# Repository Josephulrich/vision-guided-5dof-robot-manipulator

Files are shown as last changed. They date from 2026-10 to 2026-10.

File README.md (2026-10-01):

# Robot manipulateur 5 axes guidé par vision

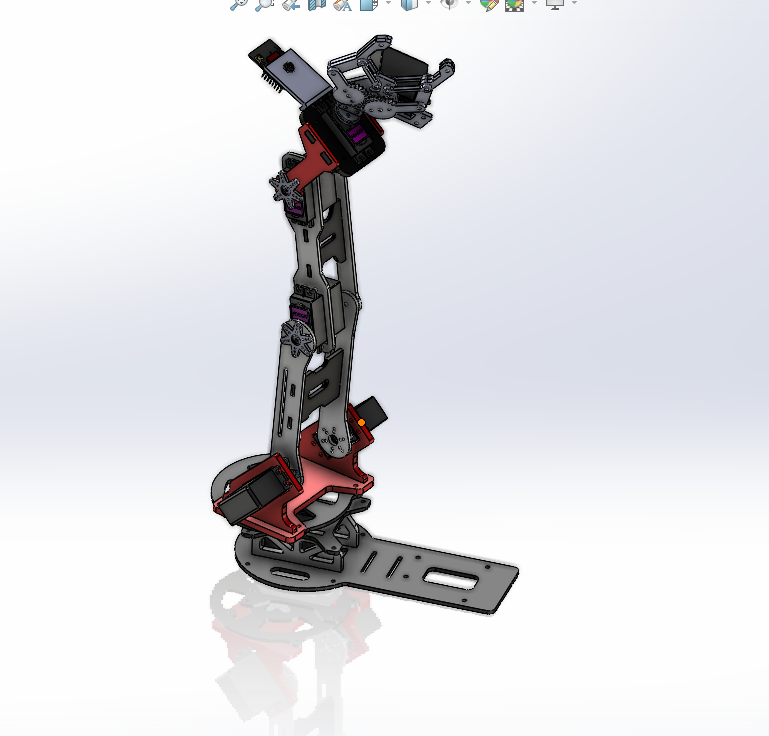
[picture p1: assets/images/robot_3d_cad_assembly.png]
Assemblage CAO du robot


Bras manipulateur robotisé à 5 degrés de liberté conçu pour détecter, atteindre et saisir des objets à l’aide d’une caméra, d’une pince motorisée et d’une chaîne de commande basée sur Arduino Mega.

Le projet réunit la conception mécanique sous SolidWorks, l’impression 3D de pièces en PLA, le dimensionnement des actionneurs, l’électronique de commande, la programmation embarquée, l’étude cinématique selon Denavit–Hartenberg, le pilotage via MATLAB et une base de vision par ordinateur développée en Python.

---

## Vue d’ensemble

| Élément | Description |
|---|---|
| Architecture robotique | Bras manipulateur série à 5 axes de type R-R-R-R-R |
| Fonction principale | Détection, positionnement et saisie d’objets |
| Structure mécanique | 3 segments principaux, 5 articulations et une pince motorisée |
| CAO | SolidWorks |
| Fabrication | Impression 3D en PLA |
| Contrôle bas niveau | Arduino Mega et Arduino IDE |
| Cinématique | Modèle Denavit–Hartenberg et trajectoires MATLAB |
| Vision | Caméra embarquée et développement de reconnaissance d’images en Python |
| Actionneurs | Servomoteurs MG995R-360°, MG996R, S07NF et servo de pince |
| Documentation | Rapport complet disponible dans le repository |

---

## Objectif du projet

L’objectif était de concevoir et de réaliser un manipulateur robotisé à cinq axes capable d’interagir avec son environnement.

Le système vise à :

- Détecter ou localiser un objet à partir d’une caméra.
- Calculer une configuration ou une trajectoire permettant au robot d’atteindre la zone ciblée.
- Commander les servomoteurs pour positionner les différents segments du bras.
- Actionner une pince afin de saisir l’objet.
- Valider les mouvements, les positions particulières et la cinématique développée sous MATLAB.

Le projet a été réalisé en première année du cycle ingénieur. Il a couvert l’étude, la conception, la fabrication, l’assemblage, la programmation et la modélisation MATLAB. La durée rapportée est d’environ deux semaines, soit 334 heures de travail cumulées.

---

## Architecture mécanique

Le robot est constitué de trois segments principaux et de cinq articulations rotatives en série.

```text
Base → Bras principal → Avant-bras → Poignet → Pince
```

### Actionneurs et dimensionnement

| Référence | Fonction | Couple calculé | Actionneur sélectionné |
|---|---|---:|---|
| `SM1` | Rotation de la base | 6,31 kg·cm | MG995R — rotation 360° |
| `SM2` | Bras principal | 6,31 kg·cm | MG996R |
| `SM3` | Avant-bras | 2,44 kg·cm | MG996R |
| `SM4` | Poignet | 0,22 kg·cm | S07NF |
| `SM5` | Ouverture / fermeture de la pince | — | Micro-servomoteur rotatif |

Les pièces ont été modélisées sous SolidWorks, puis exportées au format STL pour l’impression 3D. Les fichiers source SolidWorks et les modèles d’impression sont inclus dans le repository.

### Vue éclatée

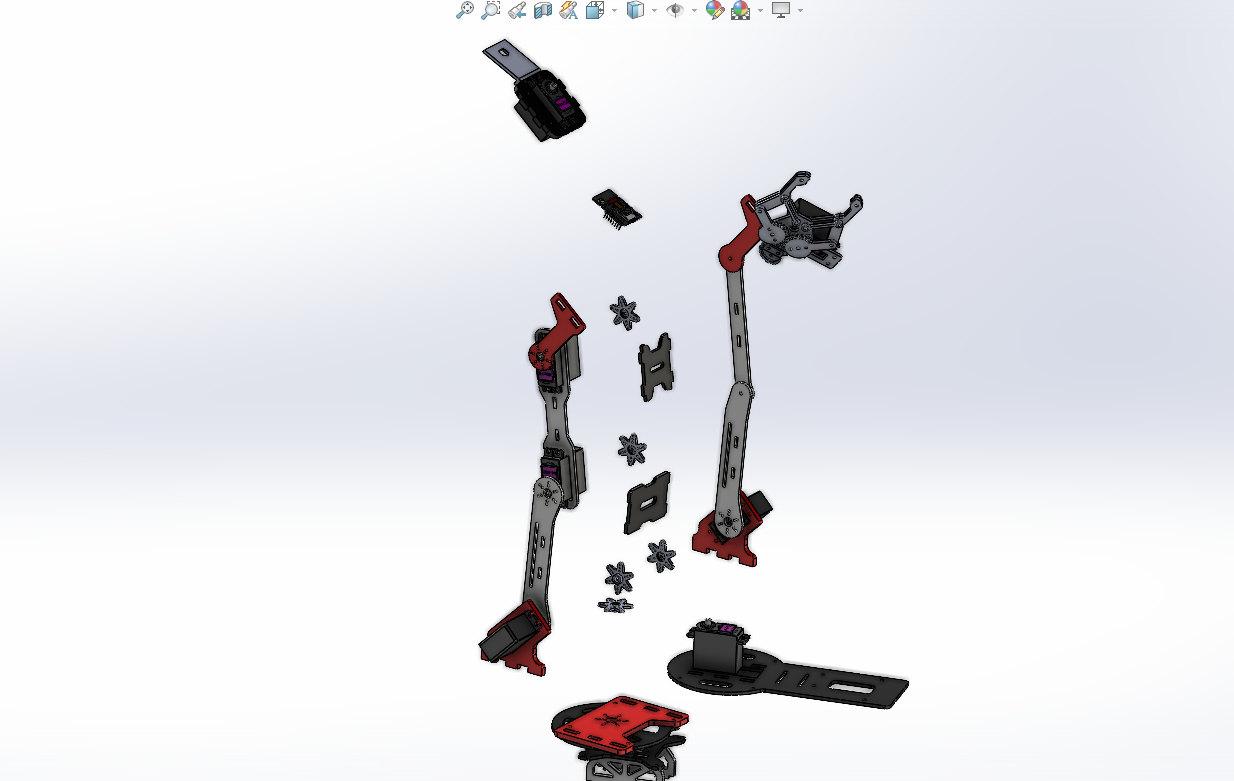
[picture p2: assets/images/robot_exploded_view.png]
Vue éclatée du bras manipulateur


### Effecteur et composants mécaniques

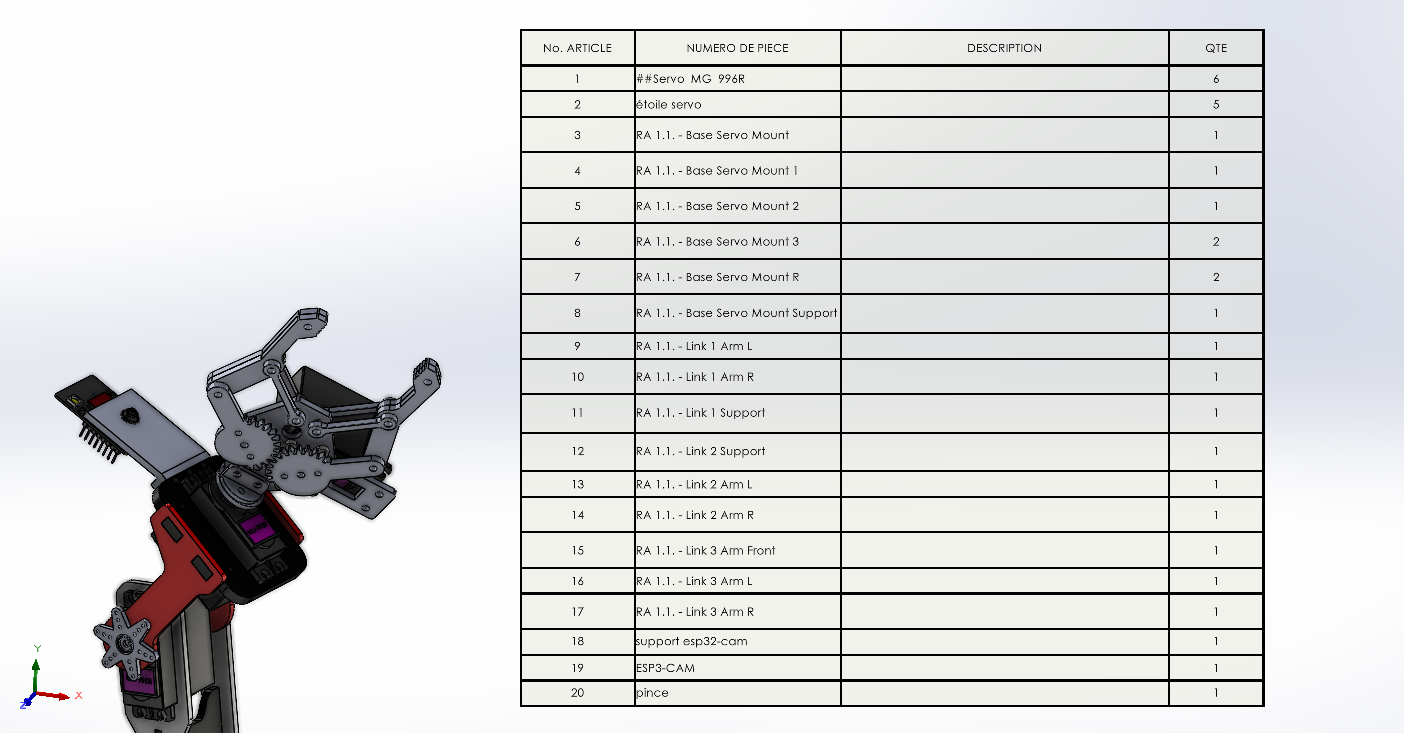
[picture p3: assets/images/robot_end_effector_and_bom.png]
Pince et nomenclature mécanique


---

## Électronique et commande

La commande des actionneurs est assurée par une Arduino Mega. L’électronique permet de relier les sorties de commande aux différents servomoteurs du manipulateur et d’intégrer l’interface caméra utilisée pour la vision.

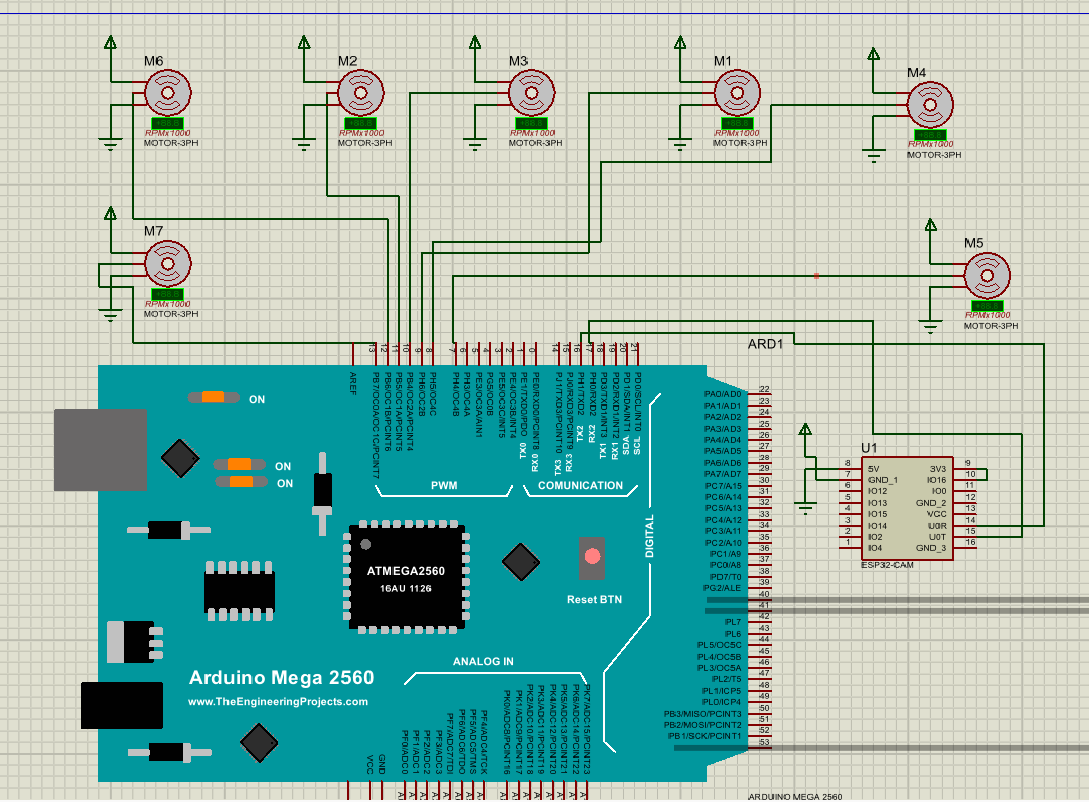
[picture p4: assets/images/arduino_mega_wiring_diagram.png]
Schéma de câblage Arduino Mega


Les fichiers du projet électronique sont disponibles dans :

```text
electronics/
├── schematics/
└── wiring/
```

Le programme Arduino se trouve dans :

```text
firmware/arduino-mega/robot_manipulator_arduino_mega/
```

---

## Cinématique et logiciel

Le modèle cinématique du robot a été étudié à l’aide de la convention de Denavit–Hartenberg. Cette modélisation sert à décrire la position et l’orientation de l’effecteur en fonction des variables articulaires.

Les interfaces et scripts MATLAB sont disponibles dans :

```text
software/matlab-kinematics/
├── interface.m
├── interface.fig
├── ROBOTOP.m
└── ROBOTOP.fig
```

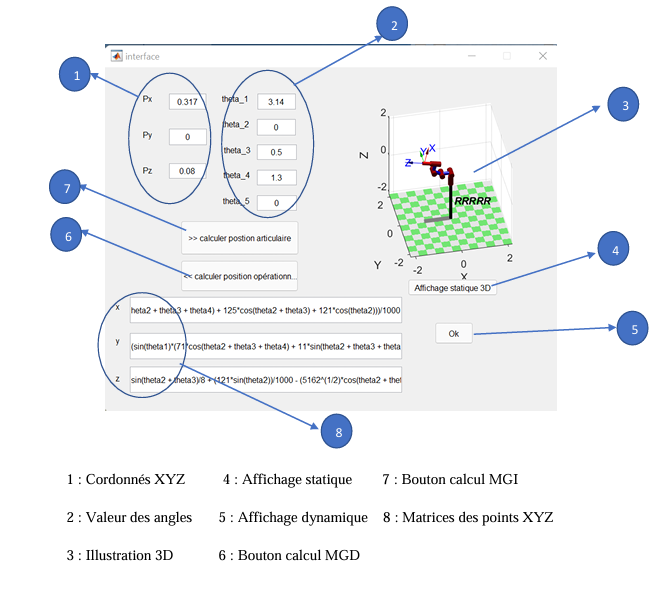
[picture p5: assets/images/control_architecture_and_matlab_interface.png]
Architecture de commande et interface MATLAB


La partie vision a été développée en parallèle sous Python. Le dossier prévu pour ces développements est :

```text
software/python-vision/
```

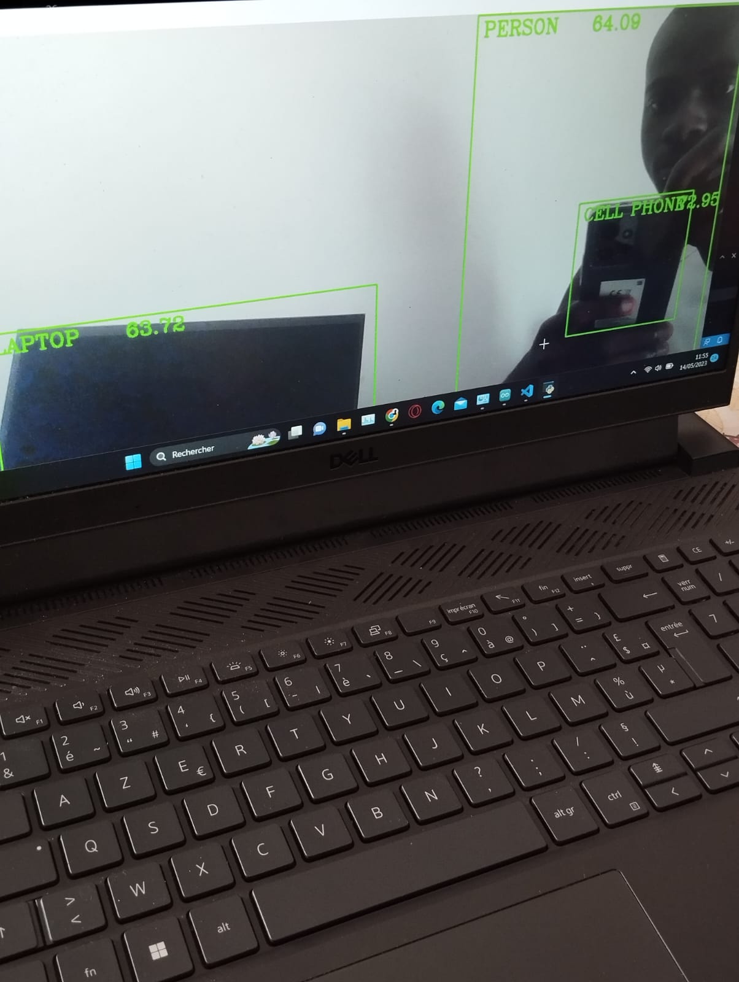
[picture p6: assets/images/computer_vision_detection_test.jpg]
Test de détection par vision


---

## Fabrication et assemblage

Les éléments mécaniques ont été imprimés en PLA, assemblés autour des servomoteurs, puis connectés au système de commande.

Les fichiers STL destinés à l’impression 3D sont fournis dans :

```text
mechanical/stl-3d-printing/
```

Les fichiers SolidWorks de conception et d’assemblage sont disponibles dans :

```text
mechanical/robot-solidworks-source/
```

### Prototype assemblé

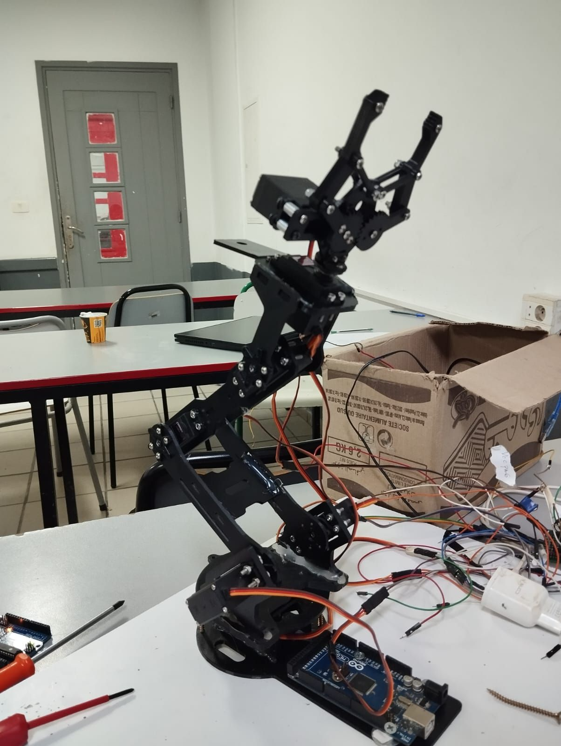
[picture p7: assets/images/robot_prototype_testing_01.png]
Prototype du robot — test 1


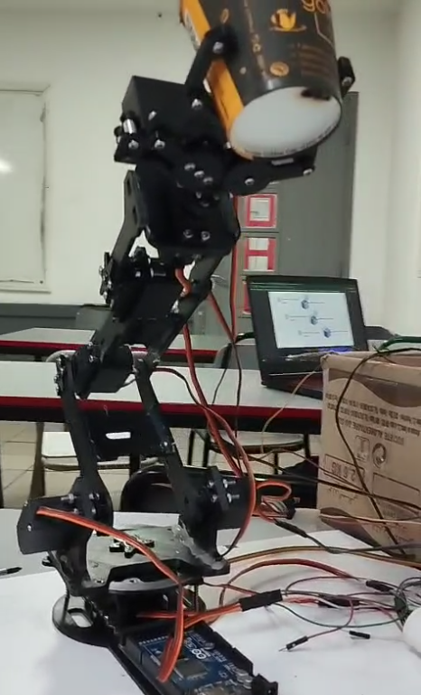
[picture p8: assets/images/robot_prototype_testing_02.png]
Prototype du robot — test 2


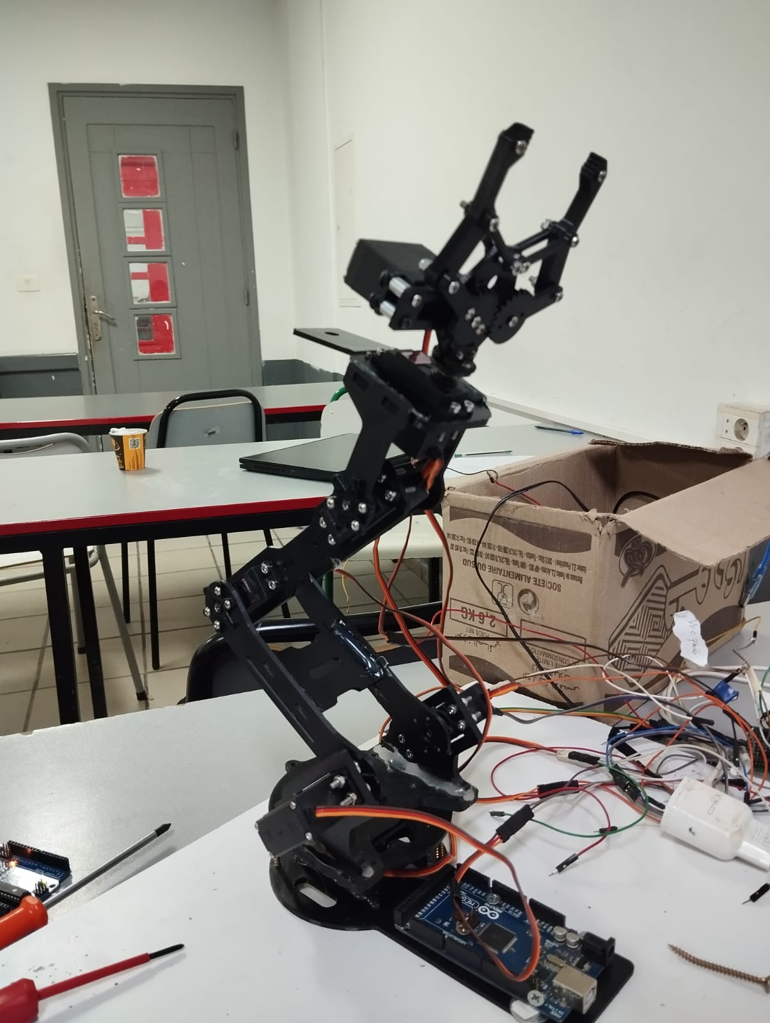
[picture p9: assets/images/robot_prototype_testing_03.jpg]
Prototype du robot — test 3


### Démonstration vidéo

La démonstration vidéo est disponible dans le repository :

[`robot_manipulator_demo.mp4`](assets/videos/robot_manipulator_demo.mp4)

> Selon le navigateur, GitHub peut proposer le téléchargement ou la lecture du fichier vidéo dans son interface.

---

## Résultats

Les principales validations obtenues durant le projet sont :

- Assemblage mécanique du bras manipulateur.
- Fabrication de composants par impression 3D.
- Commande des cinq axes par Arduino Mega.
- Tests de positions et de configurations particulières.
- Première exécution d’une cinématique générée dans MATLAB.
- Développement parallèle d’un modèle de reconnaissance d’images sous Python.
- Tests de détection par caméra documentés dans les médias du projet.

---

## Structure du repository

```text
.
├── archive/
│   ├── all-m3-sh-standard-screws-m3-hex-nut-and-flat-washer-for-m3-screw-1.snapshot.24.rar
│   └── steps.rar
│
├── assets/
│   ├── images/
│   │   ├── arduino_mega_wiring_diagram.png
│   │   ├── computer_vision_detection_test.jpg
│   │   ├── control_architecture_and_matlab_interface.png
│   │   ├── robot_3d_cad_assembly.png
│   │   ├── robot_end_effector_and_bom.png
│   │   ├── robot_exploded_view.png
│   │   ├── robot_prototype_testing_01.png
│   │   ├── robot_prototype_testing_02.png
│   │   └── robot_prototype_testing_03.jpg
│   └── videos/
│       └── robot_manipulator_demo.mp4
│
├── docs/
│   ├── calculations/
│   ├── denavit-hartenberg/
│   └── reports/
│       └── robot_manipulator_project_report.pdf
│
├── electronics/
│   ├── schematics/
│   └── wiring/
│
├── firmware/
│   └── arduino-mega/
│       └── robot_manipulator_arduino_mega/
│           └── robot_manipulator_arduino_mega.ino
│
├── mechanical/
│   ├── robot-solidworks-source/
│   └── stl-3d-printing/
│
├── software/
│   ├── matlab-kinematics/
│   └── python-vision/
│
└── README.md
```

---

## Fichiers importants

| Ressource | Emplacement |
|---|---|
| Rapport du projet | [`docs/reports/robot_manipulator_project_report.pdf`](docs/reports/robot_manipulator_project_report.pdf) |
| Code de commande Arduino | [`firmware/arduino-mega/robot_manipulator_arduino_mega/robot_manipulator_arduino_mega.ino`](firmware/arduino-mega/robot_manipulator_arduino_mega/robot_manipulator_arduino_mega.ino) |
| Scripts et interfaces MATLAB | [`software/matlab-kinematics/`](software/matlab-kinematics/) |
| Fichiers SolidWorks | [`mechanical/robot-solidworks-source/`](mechanical/robot-solidworks-source/) |
| Fichiers STL imprimables | [`mechanical/stl-3d-printing/`](mechanical/stl-3d-printing/) |
| Projet électronique | [`electronics/`](electronics/) |
| Vidéo de démonstration | [`assets/videos/robot_manipulator_demo.mp4`](assets/videos/robot_manipulator_demo.mp4) |

---

## Technologies utilisées

- SolidWorks.
- Impression 3D PLA.
- Arduino Mega.
- Arduino IDE.
- MATLAB.
- Convention de Denavit–Hartenberg.
- Programmation embarquée en C/C++ pour Arduino.
- Python pour les essais de vision par ordinateur.
- Servomoteurs MG995R, MG996R et S07NF.
- Git et GitHub pour la gestion et la documentation du projet.

---

## Améliorations possibles

- Ajouter le code Python complet de détection et de reconnaissance d’objets.
- Ajouter les paramètres Denavit–Hartenberg dans un tableau exploitable.
- Documenter les longueurs de segments, les plages angulaires et la charge utile.
- Ajouter les schémas électroniques exportés en PDF ou PNG.
- Ajouter une nomenclature complète des composants électroniques et mécaniques.
- Intégrer une cinématique inverse plus robuste avec gestion des limites articulaires.
- Ajouter une calibration caméra–robot pour transformer les coordonnées image en coordonnées du repère robot.
- Ajouter une alimentation dédiée aux servomoteurs et documenter les mesures de courant.
- Publier une vidéo courte de démonstration directement visible depuis le README.

---

## Auteur

**Joseph Mbode**  
Ingénieur en systèmes embarqués, électronique, mécatronique et conception de systèmes robotiques.

- GitHub : [@Josephulrich](https://github.com/Josephulrich)
- LinkedIn : [Joseph Mbode](https://www.linkedin.com/in/joseph-mbode)

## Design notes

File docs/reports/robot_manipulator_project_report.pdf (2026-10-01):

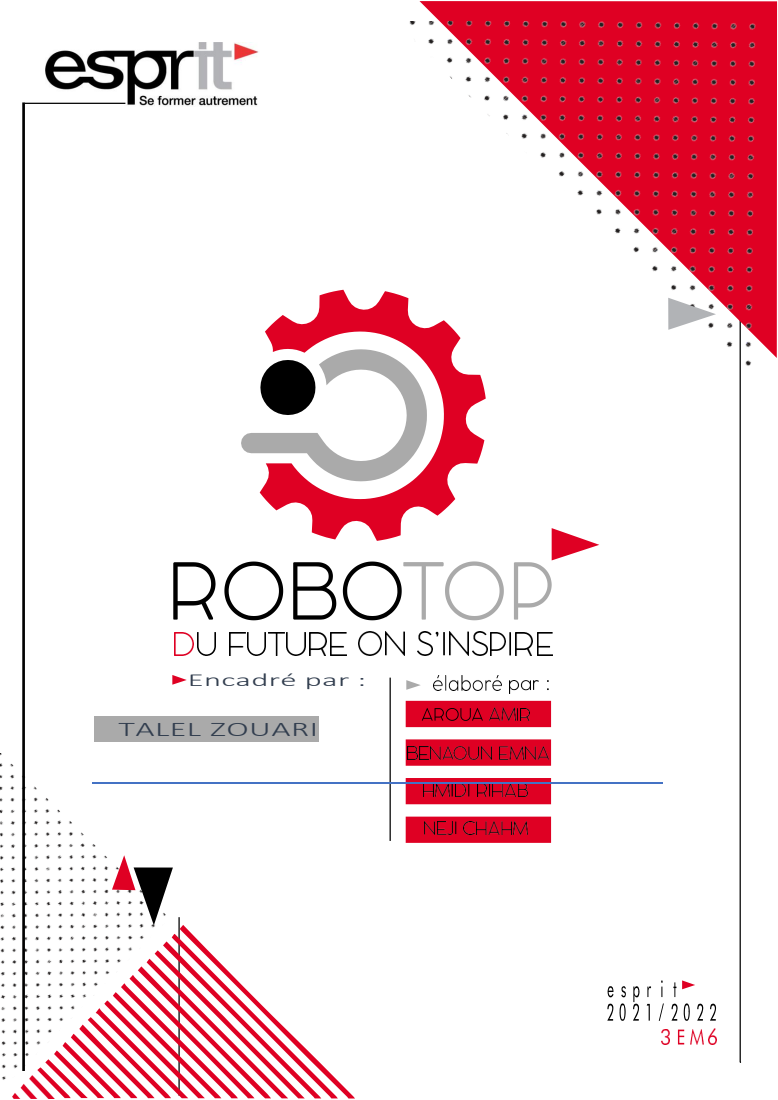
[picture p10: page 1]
Encadré par :; TALEL ZOUARI

## Nous tenons à remercier profondément Dieu, le tout puissant de

## nous avoir donné le courage, la volonté, ainsi que la santé pour

réaliser ce modeste travail.

## Nous tenons à exprimer nos vifs remerciements et nos sincères

## reconnaissances à Mr. Talel Zouari, pour sa disponibilité, ses

## conseils judicieux, ses directives et ses orientations concernant

## notre projet, tout en nous accordant sa confiance et en nous faisant

## profiter de sa large expérience tout au long de la réalisation de ce

projet de fin d’étude.

## Nous remercions les membres de jury qui ont fait l’honneur de

## participer au jugement de ce travail. Nous tenons à remercier toutes

les personnes qui ont contribué au bon déroulement de ce projet.

## Table des matières

## INTRODUCTION GÉNÉRALE

Regroupant l’électronique, l’électrotechnique, la mécanique, l’automatique et

l’informatique, la robotique est devenue depuis les années soixante-dix, une discipline à

part entière. Avec les grands progrès qu’elle a connus, la robotique s’impose de plus en

plus dans l’industrie moderne. Actuellement, les chercheurs parviennent à concevoir des

robots légers et rapides…

Les robots manipulateurs sont les plus utilisés dans les systèmes industriels, car ils

Sont flexibles permettent d’augmenter la productivité, réduire les coûts de production et

améliorer la qualité de la production, ils ont remplacé l’homme dans beaucoup de tâche en

industrie manufacturière. Ils copient les mécanismes de préhension humaine pour effectuer

des actions diverses.

Dans le cadre des projets PCR2 de 3-ème électromécanique, l’ESPRIT nous a offert

la formidable opportunité de participer à une concurrence entre collègues. Ce projet met à

l'honneur bien évidemment la robotique, fusion parfaite de la mécanique et de

l’électronique, mais aussi le travail d'équipe et la poursuite d'objectifs concrets.

Nous sommes donc 4 étudiants électromécaniciens à s'être lancé dans cette formidable

aventure avec pour seuls acquis nos connaissances scolaires et notre motivation. Le but de

notre travail consiste en la conception et la réalisation d’un robot de type manipulateur à

cinq degrés de liberté téléguidé par une application en utilisons une carte Arduino et

Bluetooth.

Ce rapport est scindé en trois chapitres comme suit :

- Dans le premier chapitre, on va présenter certaines généralités concernant la

robotique et les différents types des robots, puis nous présentons l’étude de

l’existant.

- Le deuxième chapitre est consacré à l'analyse des exigences qui contient l'analyse

de fonctionnement et l'étude théorique de ce robot.

- Finalement, le troisième chapitre est dédié à l’étude de validation de la conception

et la réalisation de ce dernier.

Nous terminons notre rapport par une conclusion générale résumant les différentes étapes

de réalisation du notre projet.

# Chapitre I :

# Etude bibliographique

# sur les robots

# manipulateurs

I. Introduction :

L’automatisation des tâches dans l’industrie a donné naissance aux robots manipulateurs.

Ces derniers prennent chaque jour une place plus importante à la fois dans le milieu

industriel.

Dans ce chapitre on va présenter quelques types de robots manipulateurs et les différentes

modélisations.

Par la suite nous allons présenter l’étude de l’existant.

II. Généralités sur la robotique :

### 1. Les différentes catégories des robots :

| • Les robots mobiles
| • Les robots sous-marins
| • Les robots volants
| • Les robots humanoïdes
| • Les robots manipulateurs
- Nous avons sélectionné quelques photos pour les catégories des robots sont les
| suivantes :

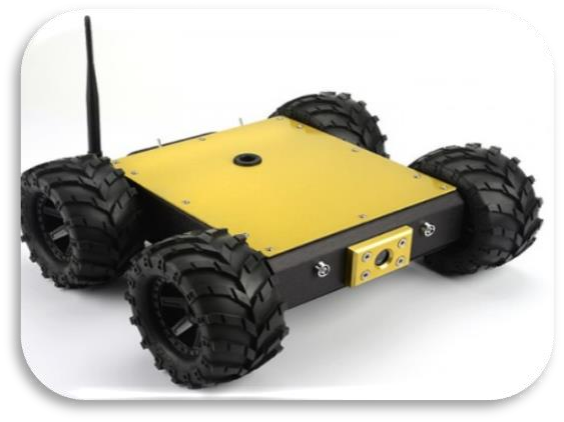
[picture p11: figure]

Robot sous-marin | robot mobile

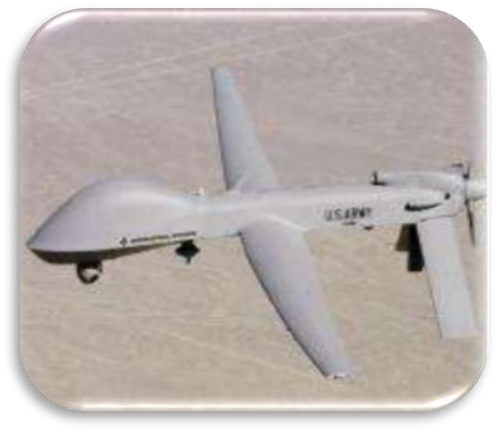
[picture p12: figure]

- En ce qui concerne notre projet, nous serons intéressés par les robots

manipulateurs.

### 2. Définitions des robots manipulateurs :

C’est un manipulateur qui doit être reprogrammable multifonctionnel conçu pour

déplacer des matériaux, des pièces, des outils ou tout autre dispositif spécialisé au moyen

d’une série de mouvements programmés et d’accomplir une variété d’autres tâches.

L’ISO (International Standard organisation) l’a défini comme étant une machine mue

par un mécanisme incluant plusieurs degrés de libertés, ayant souvent l’apparence d’un

ou plusieurs bras se terminant par un poignet capable de tenir des outils, des pièces ou

un dispositif d’inspection [01]. Pour le sens commun, un robot est un dispositif

mécanique articulé capable d’imiter certaines fonctions humaines telles que la

Robot humanoïde | Robot volant

Robots manipulteurs manipulation d’objets ou la locomotion, dans le but de remplacer l’homme pour la

réalisation de certaines tâches matérielles.

### 3. Classification des robots manipulateurs :

Au cours des années, le développement des robots a permis de distinguer entre plusieurs

classes. Il existe six classes de robots. D’abord les télémanipulateurs qui sont des bras

commandés directement par un opérateur humain. Ensuite les manipulateurs avec séquence

fixe qui admettent un contrôle automatique, mais difficile à reprogrammer. Après ce sont

les Manipulateurs avec séquence variables qui ont un contrôle automatique et qui sont

reprogrammés mécaniquement, c’est l’exemple de « Pick and Place Manipulators » ou

robot « tout ou rien ». Puis on trouve les Robots Play Back qui exécutent des séquences

sous la supervision d’êtres humains et les mémorise pour les rejouer (Play Back). Ensuite,

on trouve les robots à un contrôleur numérique où les positions des séquences sont

contrôlées par des données numériques. Enfin, on cite les robots intelligents qui peuvent

réagir dans leur environnement et à des modifications arrivant durant l’exécution.

### 4. Constituants mécaniques du robot :

Un robot manipulateur est constitué d’un ensemble de composants, ayant chacun un

rôle bien spécifique, Ces composants sont au nombre de cinq que nous citons ci-dessous :

- Actionneur : moteur, vérin
- Axe : articulation
- Corps = segment
- Effecteur = outil
- Base

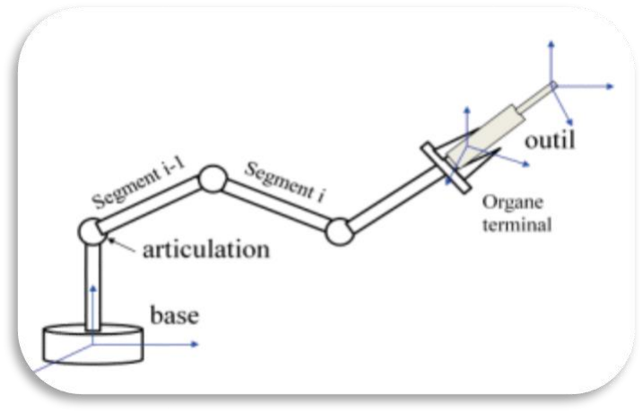
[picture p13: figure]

Structure d’un robot manipulateur

### 5. Système mécanique articulé :

Un système mécanique articulé (SMA) est un ensemble de solides reliés entre eux par

des liaisons (pivot, glissière, rotule, sphérique…) animées avec des joints mécaniques.

Dans le SMA, certaines liaisons sont motorisées. On parlera de liaisons actives, c’est le cas

des liaisons pivots. D’autres liaisons sont non motorisées ; elles sont appelées passives

telles que (les liaisons rotules…etc.).

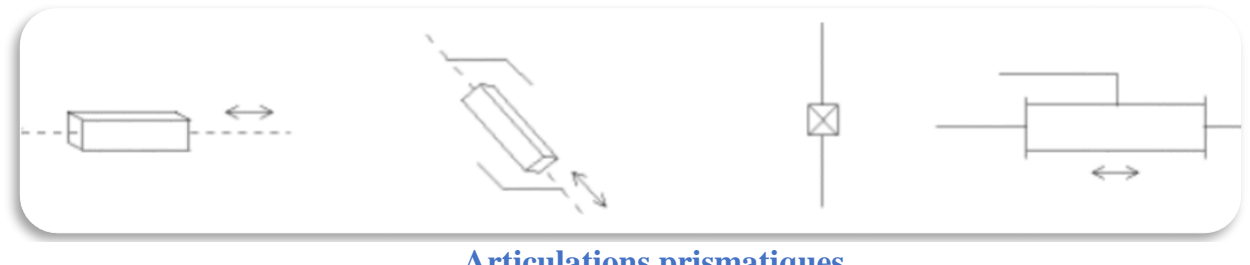
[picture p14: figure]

Différents types d’articulations sont distingués comme suit :

- Articulation prismatique : Il s'agit d'une articulation de type glissière, notée P,

réduisant le mouvement entre deux corps à une translation le long d'un axe

commun. La situation relative entre les deux corps est mesurée par la distance le

long de cet axe

- Articulation rotoïde : Il s'agit d'une articulation de type pivot, notée R, réduisant le

mouvement entre deux corps à une rotation autour d'un axe qui leur est commun.

La situation relative entre les deux corps est donnée par l'angle autour de cet axe

Articulations prismatiques

Articulations rotoïdes

### 6. Types de chaînes de la SMA :

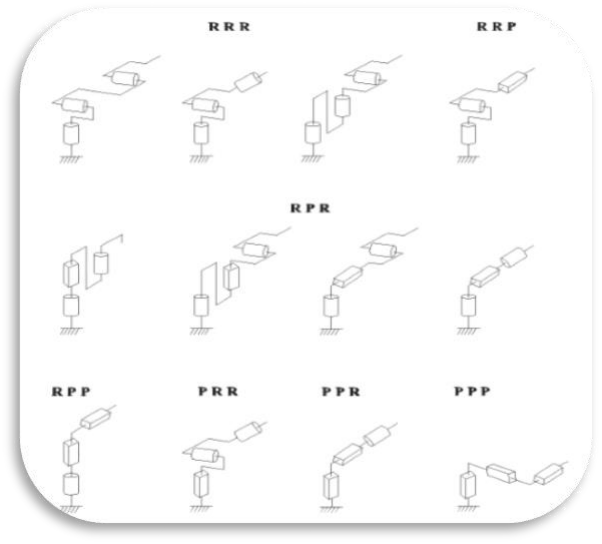
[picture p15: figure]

Concernant le chainage des articulations (mécanisme) on distingue deux types :

- Les mécanismes en chaîne simple ouverte (ou en série). Lorsque l'on parcourt le

mécanisme, on ne repasse jamais 2 fois sur la même liaison, ou sur le même solide. Ce type

de système est le plus répandu.

- Les mécanismes en chaîne complexe, tout ce qui n'est pas en série (au moins un solide

avec plus de 2 liaisons). De tels systèmes se subdivisent en 2 groupes : les chaînes

structurées en arbre, et les chaînes fermées

### 7. Les différents types des robots manipulateurs :

Les robots manipulateurs viennent sous plusieurs formes. Les formes se répartissent en en

cinq grandes catégories :

### 8. Le robot SCARA (Sélective Compliance Articulated) :

Ce type de robot al fois précis et rapide, est utilisé dans l’assemblage

Les configurations des articulations

- Les différentes configurations sont résumées comme les suivants :

C’est un robot a 3 axes série (RRT) ,3degre de liberté, son espace de travail cylindrique.

### 9. Les robots cylindriques

Ce type de robot est caractérisé par une rapidité et un espace de travail cylindrique,

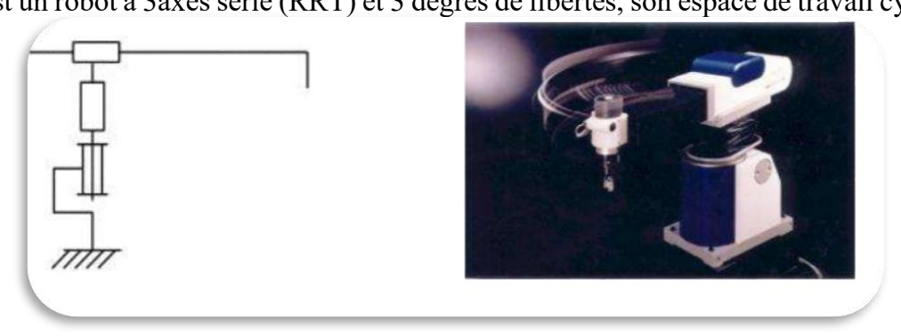
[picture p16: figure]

C’est un robot a 3axes série (RRT) et 3 degrés de libertés, son espace de travail cylindrique.

### 10. Les robots sphériques :

Ce type de robot est caractérisé par une grande charge utile.

C’est un robot a 3axes série (RRT) et 3 degrés de libertés, son espace de travail sphérique.

Robot SCARA

Robot cylindrique

Robot sphérique

### 11. Les robots cartésiens :

Ce sont des robots a 3axes perpendiculaires 2a 2, série (TTT), 3 degrés de libertés.

Ils sont caractérisés par leur très bonne précision mais ils sont lents.

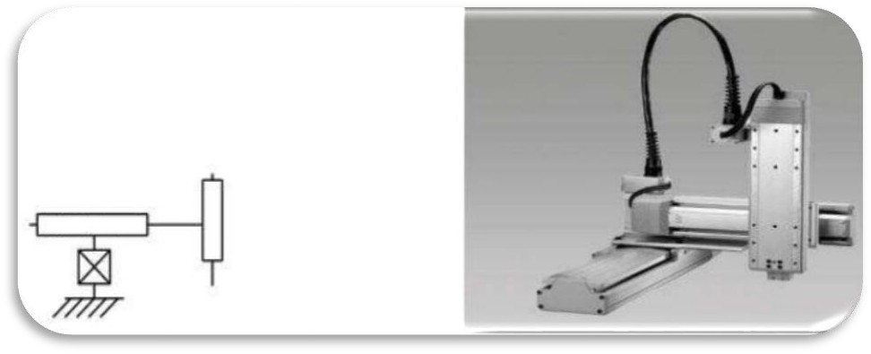
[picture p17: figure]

### 12. Les robots anthropomorphes :

Ce sont des robots a 6 axes, série, 6 rotations, et 6 degrés de libertés, ils reproduisent le bras d’un

être humain.

Robot cartésien

Robot anthropomorphes

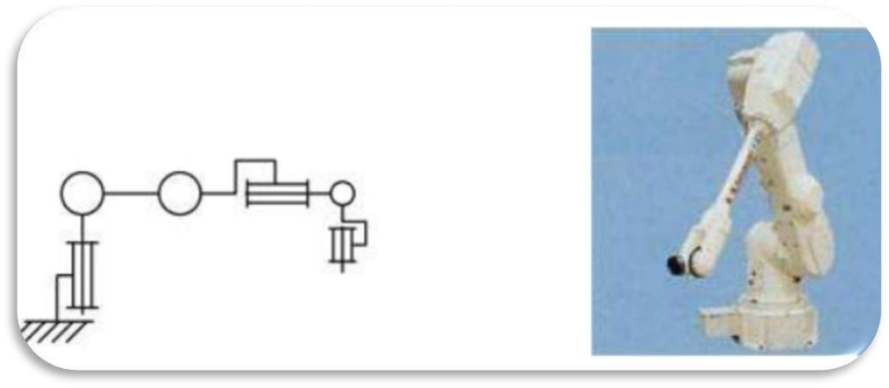
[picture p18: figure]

III. L’étude de l’existant :

Dans ce contexte, nous avons eu l'idée de mettre en place un robot manipulateur à 5 axes,

que nous appellerons ROBOTOP. Qui comprend trois segments et cinq articulations en

série (R, R, R, R, R), transportant à leurs extrémités une pince qui présente dans notre cas

un effecteur. Notre robot contient 5 parties, la première partie assure un mouvement de

rotations suivant l’axe Z, la deuxième, la troisième et la quatrième garantit un mouvement

de rotation qui se déplace sur l’axe Y, finalement, la dernière assure un mouvement de

rotation suivant l’axe X.

Nous voudrions commander ce robot pour lui permettre d'atteindre un état désiré ou

d'accomplir une tâche très spécifique avec une grande précision dans un environnement

réel, La méthode utilisée pour la manipulation consiste à utiliser une interface MATLAB

et une interface semblable à Android sur un téléphone ou une tablette. Cette interface est

reliée à une carte module Arduino et Bluetooth afin que celle-ci puisse être programmée

pour le commander.

Nous pouvons observer dans le tableau ci-dessous un récapitulatif des avantages et des

Inconvénients pour notre ROBOTOP :

| Avantages | Inconvénient
ROBOTOP | • Stable • Précision répétable • Un couple important sous un volume réduit • Efficacité accrue • Complexité mécanique faible • Légèreté | • Réponse inadéquate ou mal. • Consommation de l'énergie • Le cout est élevé

### 1. Schéma cinématique :

Le schéma de la figure suivante est un schéma cinématique du notre ROBOTOP :

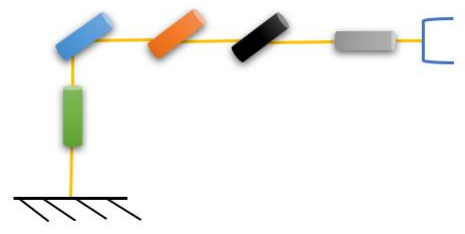
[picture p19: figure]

Schéma cinématique

IV. | Le cycle de développement du projet :
| Pour bien conduire notre projet et assurer du bon déroulement des différentes phases

nous avons opté pour le cycle de vie en cascade puisque les besoins ont été bien cernés sans

ambigüité. Le modèle de cycle de vie en cascade est développé dans les années 1970 par

W. Royce, l'avantage de ce modèle est de proposer au fur et à mesure une démarche de

réduction des risques, en minimisant au fur et à mesure l'impact des incertitudes. L'impact

d'une incertitude dans la phase de développement étant plus faible que l'impact d'une

incertitude dans la phase de conception ou de spécification. Plus le projet avance plus les

risques diminuent.

Le schéma détaillé du cycle de développement se présente ci-dessous.

Schéma de cycle de développement

V. Conclusion :

Les robots manipulateurs sont très intéressants puisqu’ils ont prouvé qu’ils

étaient capables de se substituer à l’être humain dans plusieurs tâches

difficiles à réaliser et d’effectuer de bonnes performances, nous avons bien

présenté l’étude bibliographique dans ce chapitre. Le chapitre suivant décrit

l’étude théorique et l’analyse fonctionnelle.

### analyse de besoin

### conception mecanique et electrique

### programmation

### realisation et validation

# Chapitre II :

# L’analyse des

# Exigences

I. Introduction :

Le démarche de l’analyse fonctionnelle aide à mettre le produit dans un

environnement en s’appuyant sur les résultats des chapitres précédents et en prenants en

considération tous les facteurs existants pour une étude fiable ainsi que les performances

des robots dépendent fortement de celles des actionneurs, de la partie commande, qui ont

de ce fait une importance primordiale. Ce chapitre a l’objectif d’étudier les matériels utiles

à la conception et la réalisation de notre projet.

II. Modélisation du système :

Afin de modéliser cette machine, nous présentons la fonction générale décrite dans la

figure ci-dessous.

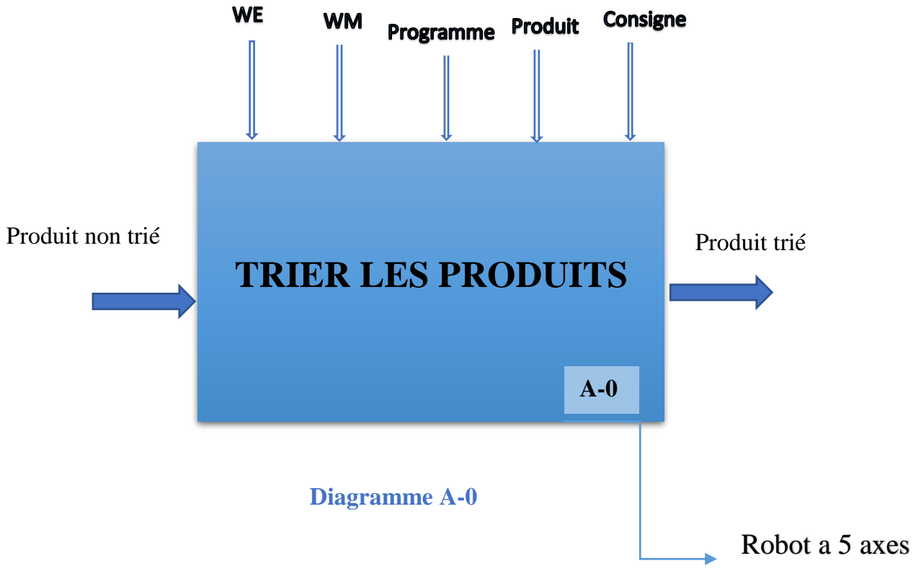
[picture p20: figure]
TRIER LES PRODUITS; Produit non trié; Produit trié; Robot a 5 axes; Diagramme A-0

III. Analyse fonctionnelle :

### 1. Définition :

Dans notre travail on a utilisé l’analyse fonctionnelle est une démarche qui consiste à

rechercher et à caractériser les fonctions offertes par un produit pour satisfaire les besoins

de son utilisateur. La démarche est généralement conduite en mode projet et peut être

utilisée pour créer (conception) un produit(projet).

### 2. Le diagramme Bête à cornes :

Pour énoncer le besoin il suffit de poser trois questions et trouver leurs réponses dans le

but d’exprimer avec précision l’objectif et la limite d’étude.

Le diagramme Bête à cornes

### 3. Le diagramme pieuvre :

Le diagramme pieuvre est la représentation graphique des interactions d'un produit avec

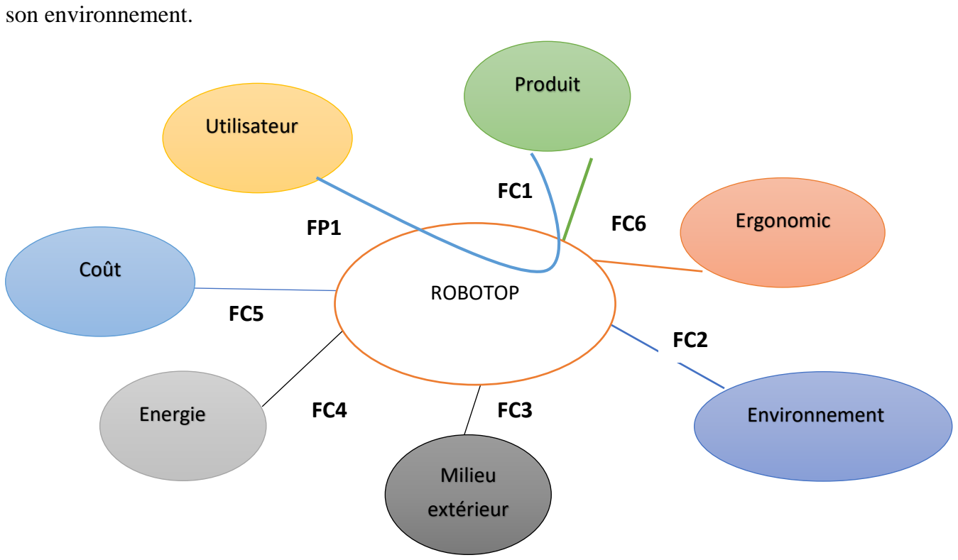
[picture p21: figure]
ROBOTOP; son environnement.; Produit; Energie; Utilisateur; Milieu; extérieur; Environnement; Coût; Ergonomic

### 4. La liste des fonctions :

Afin de décrire les combinaisons entre les fonctions que nous avons utilisées, la liste des

fonctions est la suivante.

FP1 : éviter l’utilisateur de Manipuler les produits

FC1 : déplacer le produit

FC2 : Contribuer au respect de l’environnement

FC3 : Résister au milieu extérieur

FC4 : Utiliser les énergies disponibles avec le minimum de consommation

Graphe des interactions (pieuvre)

FC5 : Être peu coûteux.

FC6 : Permettre des réglages pour une utilisation optimale selon les types de manipulation.

### 5. Tri croisée :

Pour la hiérarchisation des fonctions de service, on utilise un outil appelé « Tri croisée »

qui consiste à comparer ces fonctions entre elle par des notes de supériorité allant de 0 à 3 :

0 : Pas de supériorité.

1 : Légèrement supérieur.

2 : Moyennement supérieur.

2 : Nettement supérieur.

| FC1 | FC2 | FC3 | FC4 | FC5 | FC6 | Point | %
FP1 | FP1\1 | FP1\2 | FP1\2 | FP1\2 | FP1\1 | FP1\3 | 11 | 32.35
| FC1 | FC1\2 | FC1\1 | FC4\0 | FC1\1 | FC1\2 | 6 | 17.65
| | FC2 | FC2\0 | FC4\1 | FC5\1 | FC2\1 | 3 | 8.8
| | | FC3 | FC4\1 | FC3\1 | FC5\2 | 4 | 11.8
| | | | FC4 | FC4\2 | FC6\2 | 4 | 11.8
| | | | | FC5 | FC6\2 | 2 | 5.8
| | | | | | FC6 | 4 | 11.8
| | | | | | Total | 34 | 100
- La hiérarchisation des fonctions de services permet de déterminer les fonctions

représentant une priorité. Ainsi qu’aucune des fonctions ne doit avoir une priorité

de 0%, cela voudrait dire que cette fonction n’a pas lieu d’être. Si cela se présente,

un pourcentage corrigé est ajouté, et la fonction à 0% prend une valeur symbolique

de 1% en prenant les restes après virgule des pourcentages importants.

Nous avons mis au point l'histogramme hiérarchique de la fonction de service qui est

illustré ci-dessous.

Series 1

Histogramme des souhaits

IV. Diagramme F.A.S.T :

Pour réaliser cette phase d’analyse fonctionnelle du produit, nous allons utiliser l’outil

F.A.S.T << Function Analyse Système Technique >>. Cet outil de création permet, à

partir d’une fonction de service, par un questionnement d’aboutir aux fonctions

techniques et aux solutions constructives associées.

Le diagramme que nous avons à créer est comme le suivant.

### Hiérarchisation des fonctions de services

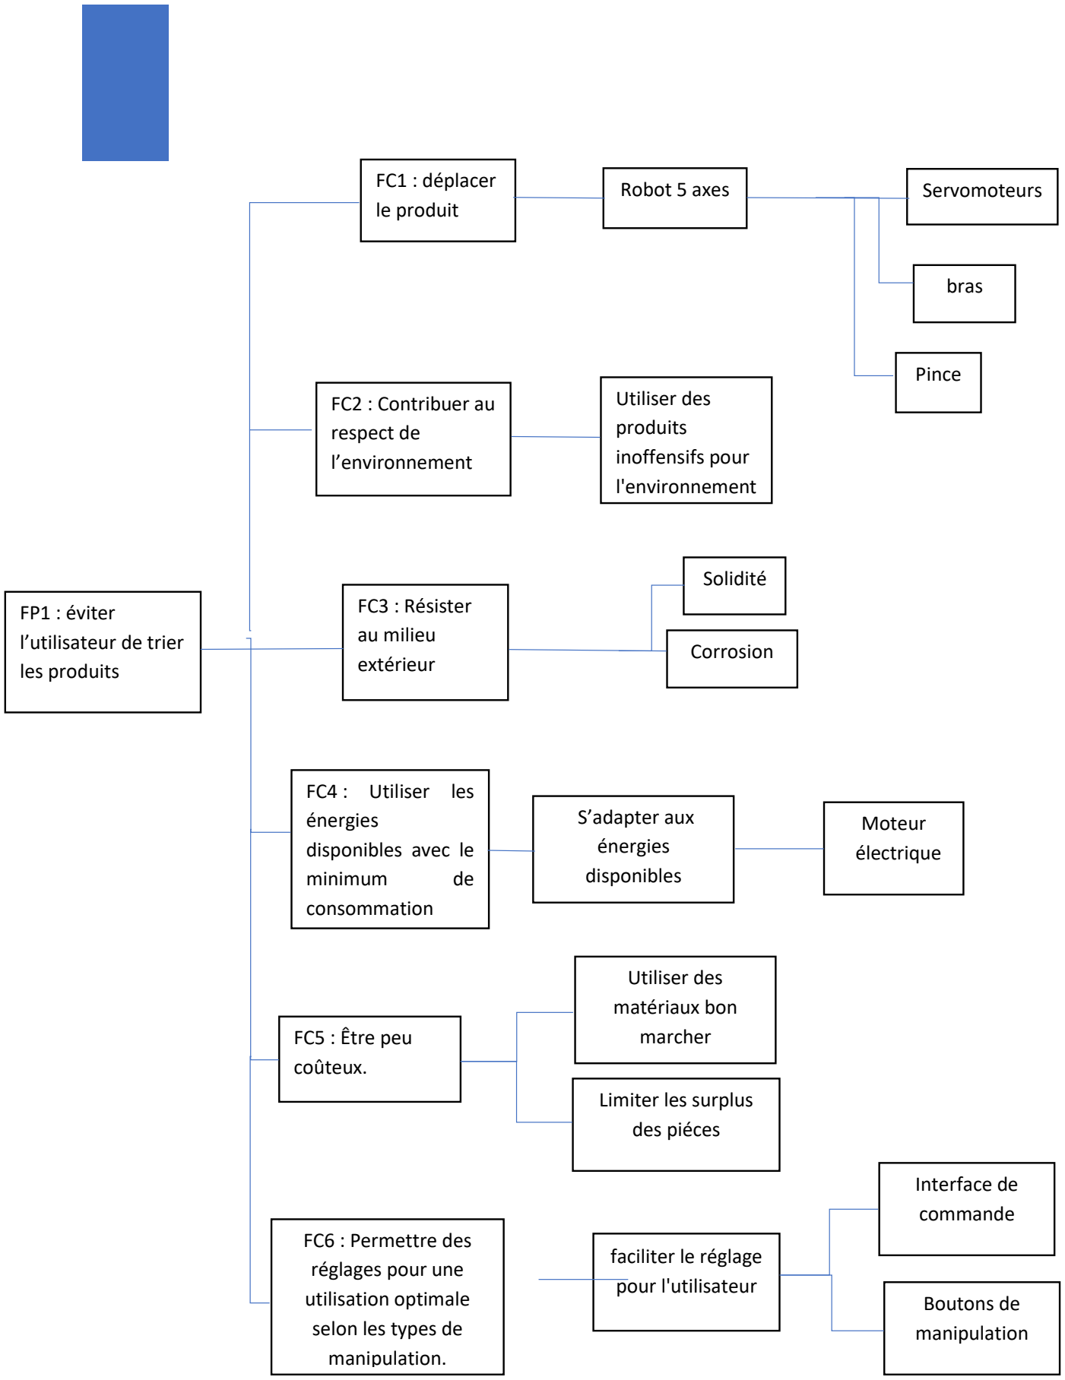
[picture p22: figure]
FP1 : éviter l’utilisateur de trier les produits; Robot 5 axes; FC6 : Permettre des réglages pour une utilisation optimale selon les types de manipulation.; Moteur électrique; FC1 : déplacer le produit; FC4 : Utiliser les énergies disponibles avec le; minimum; consommation; bras; Servomoteurs; FC3 : Résister au milieu extérieur; FC2 : Contribuer au respect de l’environnement; FC5 : Être peu coûteux.; Interface de commande; Boutons de manipulation; Utiliser des produits inoffensifs pour l'environnement; Limiter les surplus des piéces; Utiliser des matériaux bon marcher; S’adapter aux énergies disponibles; faciliter le réglage pour l'utilisateur; Corrosion; Solidité; Pince

V. Mode de fonctionnement :

### 1. Présentation de moteur électrique :

Une machine électrique est un dispositif électromécanique (https://fr.wikipedia.org/wiki/%C3%89lectrom%C3%A9canique) fondé sur

l'électromagnétisme (https://fr.wikipedia.org/wiki/%C3%89lectromagn%C3%A9tisme) permettant la conversion d'énergie électrique (https://fr.wikipedia.org/wiki/%C3%89nergie_%C3%A9lectrique) par exemple

en travail (https://fr.wikipedia.org/wiki/Travail_d%27une_force) ou énergie mécanique. (https://fr.wikipedia.org/wiki/%C3%89nergie_m%C3%A9canique) Ce processus est réversible et peut servir à produire de

l'électricité :

- les machines électriques produisant de l'énergie électrique à partir d'une

énergie mécanique sont communément appelées

des génératrices, (https://fr.wikipedia.org/wiki/G%C3%A9n%C3%A9rateur_%C3%A9lectrique) dynamos (https://fr.wikipedia.org/wiki/Dynamo) ou alternateurs (https://fr.wikipedia.org/wiki/Machine_synchrone) suivant la technologie utilisée ;

- Les machines électriques produisant une énergie mécanique à partir d'une

énergie électrique sont communément appelées des moteurs. (https://fr.wikipedia.org/wiki/Moteur)

FC1 : déplacer
le produit

servomoteur
s

Robot 5 axes

Moteur
electrique

FC4 : Utiliser les
énergies
disponibles avec le
minimum | de
consommation

S’adapter aux
énergies
disponibles

### 2. Définition d’un servomoteur :

Un servomoteur est comme son nom l'indique, un moteur mais avec quelques

spécificités en plus. Contrairement à un moteur classique qui est utilisé pour tourner avec

une vitesse proportionnelle à un courant ou à une tension, pour obtenir une position. Il

effectue une rotation suivant un angle déterminé. Le plus souvent l'angle est compris entre

0 et 180° puis il garde cette position.

Un servomoteur est composé par :

-Un moteur a courant continue.

- Un réducteur.
- Une carte électronique pour le contrôle.
- Un potentiomètre

Moteur électrique

Un servomoteur

En vue de choisir le type de servomoteur, nous mentionnerons les avantages et les

inconvénients qui sont illustrés dans le tableau ci-dessous.

### 3. Définitions de l’interface de ligne de commande :

Une interface en ligne de commande ou ILC (en anglais command line interface,

couramment abrégé CLI) est une interface homme-machine (https://fr.wikipedia.org/wiki/Interface_homme-machine) dans laquelle la

communication entre l'utilisateur et l'ordinateur (https://fr.wikipedia.org/wiki/Ordinateur) s'effectue en mode texte (https://fr.wikipedia.org/wiki/Mode_texte) :

- L’utilisateur tape une ligne de commande, (https://fr.wikipedia.org/wiki/Commande_informatique) c'est-à-dire du texte au clavier pour

demander à l'ordinateur d'effectuer une opération ;

- L’ordinateur affiche du texte correspondant au résultat de l'exécution des

commandes tapées ou à des questions qu'un logiciel pose à l'utilisateur.

Une interface en ligne de commandes peut servir aussi bien pour lancer l'exécution de

divers logiciels (https://fr.wikipedia.org/wiki/Logiciel) au moyen d'un interpréteur de commandes, (https://fr.wikipedia.org/wiki/Interpr%C3%A9teur_de_commandes) que pour les dialogues avec

l'utilisateur de ces logiciels. C'est l'interaction (https://fr.wikipedia.org/wiki/Interactions_homme-machine) fondamentale entre un homme et un

ordinateur (ou tout autre équipement informatique).

- Nous avons souhaité maîtriser MATLAB comme interface pour contrôler ce robot

puisque nous avons découvert que ce logiciel est le plus puissant et efficace.

Les avantages | Les inconvénients
- Couple important • Vitesse élève • Haute Précision | • Prix élevés • Contre réaction nécessaire • (Pas de boucle ouverte)

Tableau présentant les avantages et les inconvénients des servomoteurs

FC6 : Permettre des
réglages pour une
utilisation optimale
selon les types de
manipulation.

Interface de
commande

faciliter le
réglage pour
l'utilisateur

### 4. Présentation de logiciel MATLAB :

MATLAB (« matrix laboratory ») est un langage de script (https://fr.wikipedia.org/wiki/Langage_de_script) émulé par un environnement de

développement (https://fr.wikipedia.org/wiki/Environnement_de_d%C3%A9veloppement) du même nom ; il est utilisé à des fins de calcul numérique. (https://fr.wikipedia.org/wiki/Calcul_num%C3%A9rique) Développé par

la société The MathWorks, (https://fr.wikipedia.org/wiki/The_MathWorks) MATLAB permet de manipuler des matrices, (https://fr.wikipedia.org/wiki/Matrice_(math%C3%A9matiques)) d'afficher

des courbes (https://fr.wikipedia.org/wiki/Courbe) et des données, de mettre en œuvre des algorithmes, (https://fr.wikipedia.org/wiki/Algorithme) de créer des interfaces

utilisateurs, (https://fr.wikipedia.org/wiki/Interactions_homme-machine) et peut s’interfacer avec d’autres langages comme le C, (https://fr.wikipedia.org/wiki/C_(langage)) C++, (https://fr.wikipedia.org/wiki/C%2B%2B) Java, (https://fr.wikipedia.org/wiki/Java_(langage)) et Fortran. (https://fr.wikipedia.org/wiki/Fortran)

### 5. Modélisation :

Quelle que soit la tâche que doit réaliser un robot manipulateur, il est important de maitriser

la position et le déplacement de son outil de travail (organe terminal). La modélisation

géométrique qui est une configuration définie par un ensemble de variables articulaires

traduisant les déplacements relatifs d’un corps par rapport au précédent.

Les modèles mathématiques nécessaires sont :

- Les modèles géométriques directs et inverses qui expriment la situation de l’organe

terminal en fonction des variables articulaire et inversement.

- -les modèles cinématiques directes et inverse qui expriment les vitesses de l’organe

terminal en fonction des variables articulaires et inversement.

LOGO de logiciels MATLAB

A. Modèle géométrique direct :

Pour pouvoir effectuer le calcul de l'équation géométrique directe d'un robot à corps rigides

et sans jeux au niveau des articulations nous devons recourir à une méthode systématique

et générale qui doit être appliquée afin de définir la position et l'orientation relatives de

deux corps consécutifs, la méthode de Denavit-Hartenbergest la plus répandue.

Nous décrirons cette méthode en détail plus tard au cours de notre calcul.

B. Modèle géométrique inverse :

Le modèle géométrique inverse MGI consiste à définir les variables articulaires qui

correspondent à une situation spécifique de l'organe terminal, lorsqu’elles existent.

Trois méthodes de calcul de MGI sont connues :

- La méthode de Paul, qui convient pour la plupart des robots industriels.
- La méthode de Peiper, qui permet de résoudre le problème pour les robots à six

degrés de liberté avec trois articulations rotoı̈des ou trois articulations prismatiques.

Nous développerons par la suite la méthode de Paul dans notre calcul.

C. Interface et calcul :

Tout d'abord, nous commençons par introduire les calculs MGD sur l'interface MATLAB

Les paramètres géométriques de DENAVIT-HERTENBERG(DH) du robot à

commander sont donnés dans le tableau suivant :

Corps | ϴi | di | ai | αi
1 | 0 | L0 | 0 | π 2
2 | 0 | 0 | L1 | 0
3 | 0 | 0 | L2 | 0
4 | 0 | 0 | L3 | π 2
5 | 0 | L4 | 0 | 0

Les paramètres tii, di, ai, αi sont appelés : les paramètres de DENAVIT-

HERTENBERG(DH).

- tii : angle entre les axes Xi-1 et Xi correspondant à une rotation autour de Zi-1
- αi : angle entre les axes Zi-1 et Zi correspondant à une rotation autour de Xi
- ai : distance entre Zi-1 et Zi le long de Xi
- di : distance entre Xi-1 et Xi le long de Zi-1

pxx=(121*cos(theta1)*cos(theta2))/1000 + (11*cos(theta4)*(cos(theta1)*cos(theta2)*sin(theta3) +

cos(theta1)*cos(theta3)*sin(theta2)))/1000 - (71*cos(theta4)*(cos(theta1)*sin(theta2)*sin(theta3) -

cos(theta1)*cos(theta2)*cos(theta3)))/1000 - (71*sin(theta4)*(cos(theta1)*cos(theta2)*sin(theta3) +

cos(theta1)*cos(theta3)*sin(theta2)))/1000 -

(11*sin(theta4)*(cos(theta1)*sin(theta2)*sin(theta3)cos(theta1)*cos(theta2)*cos(theta3)))/1000 -

(cos(theta1)*sin(theta2)*sin(theta3))/8 + (cos(theta1)*cos(theta2)*cos(theta3))/8

pyy=(121*cos(theta2)*sin(theta1))/1000 +(11*cos(theta4)*(cos(theta2)*sin(theta1)*sin(theta3)

+cos(theta3)*sin(theta1)*sin(theta2)))/1000 - (71*cos(theta4)*(sin(theta1)*sin(theta2)*sin(theta3) -

cos(theta2)*cos(theta3)*sin(theta1)))/1000 - (71*sin(theta4)*(cos(theta2)*sin(theta1)*sin(theta3) +

cos(theta3)*sin(theta1)*sin(theta2)))/1000 - (11*sin(theta4)*(sin(theta1)*sin(theta2)*sin(theta3) -

cos(theta2)*cos(theta3)*sin(theta1)))/1000 - (sin(theta1)*sin(theta2)*sin(theta3))/8 +

(cos(theta2)*cos(theta3)*sin(theta1))/8

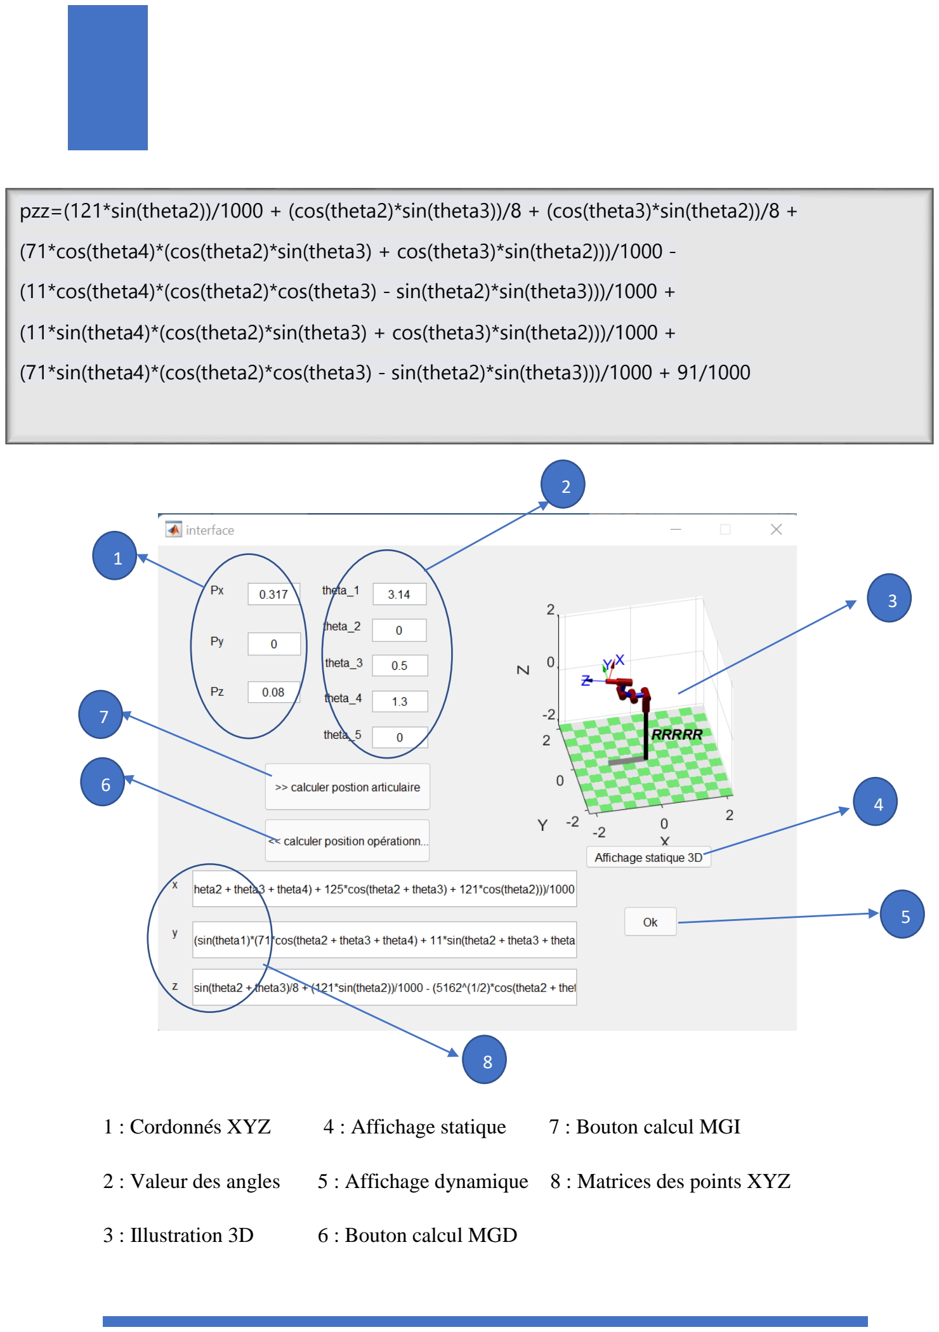
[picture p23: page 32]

1 : Cordonnés XYZ | 4 : Affichage statique | 7 : Bouton calcul MGI
2 : Valeur des angles | 5 : Affichage dynamique 8 : Matrices des points XYZ
3 : Illustration 3D | 6 : Bouton calcul MGD

pzz=(121*sin(theta2))/1000 + (cos(theta2)*sin(theta3))/8 + (cos(theta3)*sin(theta2))/8 +

(71*cos(theta4)*(cos(theta2)*sin(theta3) + cos(theta3)*sin(theta2)))/1000 -

(11*cos(theta4)*(cos(theta2)*cos(theta3) - sin(theta2)*sin(theta3)))/1000 +

(11*sin(theta4)*(cos(theta2)*sin(theta3) + cos(theta3)*sin(theta2)))/1000 +

(71*sin(theta4)*(cos(theta2)*cos(theta3) - sin(theta2)*sin(theta3)))/1000 + 91/1000

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
VI. L’étude théorique :

Afin de commander ce robot, nous ferons l'étude théorique nécessaire et nous

déterminerons le choix des matériels pour la conception.

- Concernant le choix des matériels on a commencé tous d’abord par le choix des
| moteurs, on a décidé d’utiliser les servos moteurs car ils comprennent un système à
| trois fils d’alimentation, mise à la terre et contrôle alors que le moteur à courant
| continu est un système à deux fils d’alimentation et mise à la terre. Autrement dit,
| les servos moteurs sont des systèmes qu’on peut commander par le fil signale
| (contrôle) à atteindre une position bien déterminer et c’est ce dont on a besoin pour
| notre robot.

### 1. Calcul théorique :

Afin de pouvoir effectuer les calculs nécessaires, nous avons opté pour un petit modèle

pour faciliter l’étude.

Nous commençons par le choix des servomoteurs :

On a posé pour ce calcul le poids :

- Pour le servomoteur 1, 2et 3 responsable de la rotation de base, le servomoteur doit

supporter le poids de toutes les parties de manipulation.

- La charge maximale qu’il doit supporter et de (40g) par mesure de sécurité tout en

assurant une rotation de 360°

- Pour cela nous n’avons pas trouvé mieux que le MG995R-360° qui est le seul

servo- moteur disponible sur le marché et qui correspond à notre besoin, son unité

est complète avec un fil de 30 cm et un connecteur femelle à 3 broches qui convient

à la plupart des récepteurs. Ce servo standard à couple élevée existe en deux

versions 120° et 360°.

- Pour le servo (4) de la rotation du bras nous allons utiliser le MG996R puisqu’il peut

supporter le poids.

- Pour le servo moteur (5) responsable de la rotation du poignet ou à exploiter le

minuscule et léger servo moteur S07NF qui est caractérisé avec une puissance de

sortie élevée.

Le produit= 40 g
Le Servomoteur=60g

Pince=100g

Sm5=0.25*0.86=0.22 Kg/Cm

Sm4=0.25*(0.86+7.18) +0.06*7.18=2.44

Kg/Cm

Sm3=0.25*(12.5+0.86+7.18)

+0.06*(7.18+12.5) =6.31 Kg/Cm

Sm2=0.25*(12.5+0.86+7.18+e)

+0.06*(7.18+12.5+e) +0.06*e=6.31 Kg/Cm

En tenant compte des distances :

Offset = 9.1cm

Bras 1 = 12.1cm

Bras 2 = 12.5cm

Bras 3 = 7.18cm

e = tends vers 0

Distance entre Sm5 et la pince = 0.86 cm

Nous nous dirigeons alors vers la carte Arduino que nous utiliserons au cours de ce projet.

### 2. Présentations Carte Arduino méga 2560 :

Parlant de l’Arduino, on a choisi l’Arduino MEGA 2560 doté d’un fonctionnement

identique que l’Arduino uno. Mais elle possède un nombre de port supérieur (16 analogique

et 54 numérique contre 6 analogique et 14 numérique) et elle dispose de 256 KB de

mémoire flash plus que l’Arduino uno qui possède seulement de 32KB.

Ces caractéristiques et de la façon suivant :

- Tension de fonctionnement : 5V
- Tension d’entrée : 7-12V
- Broches d'E / S numériques : 54
- Broches d'entrée analogique : 16
- Mémoire flash : 256 Ko
- LED_BUILTIN : 13
- Longueur : 101,52 mm
- Largeur : 53,3 mm
- Poids : 37 g

Ensuite, nous utiliserons le module Bluetooth pour la connexion entre la carte Arduino et

l'application.

### 3. Présentation module Bluetooth HC05 :

Afin d’assurer la communication entre l’Arduino et le robot, on a besoin d’une liaison

Bluetooth en utilisant le module HC-05, Cela nous permet de connecter la carte Arduino à

un autre système afin d’envoyer et de recevoir des données.

Ces caractéristiques et de la façon suivant :

- Alimentation : 3,6 à 6 Vcc (régulateur 3 Vcc intégré)
- Bluetooth : 2.0

- Portée : jusqu'à 10 mètres
- Liaison série : 4800 à 1382400 bauds
- Antenne : 2,4 GHz intégrée
- Sorties : Key, Vcc, GND, TXD, RXD et State.
- Configuration via commandes AT
- Longueur du cordon : environ 20 cm
- Dimensions : 35 x 16 x 12 mm

VII. Conclusion

En guise de conclusion, dans ce chapitre nous avons détaillé le choix de nos matériels et

l’analyse fonctionnelle de ce robot.

Module Bluetooth HC-05

# Chapitre III :

# Conception et

# réalisation

I. Introduction :

Après la présentation et l'analyse du fonctionnement du système et en déterminant tout le

matériel nécessaire à notre robot. Nous poursuivrons la dernière partie de notre projet et

nous détaillerons les étapes successives de la construction mécanique et électrique de notre

robot.

Nous allons développer les différents systèmes inhérents à notre solution de sorte que nous

puissions développer un robot qui est le plus modulable et fiable que possible.

Ce chapitre porte sur l’utilisation de deux logiciels un pour la conception et l’autre pour la

programmation afin d’élaborer l’application permettant la supervision de notre projet.

II. Conception mécanique :

Plusieurs logiciels de conception mécanique existent sur marché qui servent à la conception

de notre robot. SolidWorks utilisé dans notre projet est parmi les logiciels courants les plus

utilisés.

### 1. Présentation de logiciel « SOLID WORKS » :

On a utilisé le logiciel Solide Works qui est un logiciel de conception assistée par

ordinateur.il permet de réaliser de la modélisation 2D et 3D. Il est relativement facile à

utiliser et à prendre en main, et est également très répandu dans lycées, et dans les filières

technologiques, où étudiants l'utilisent pour les sciences de l'ingénieur et la technologie.

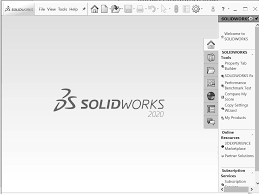
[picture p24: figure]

Interface principale de SolideWorks

Nous allons modéliser toutes les pièces de ce robot qui sont illustrées à dossier de mise en

plan.

Après l’assemblage des différents composants, nous espérons arriver à construire le robot

dans cette forme finale.

Vue de face de la conception final

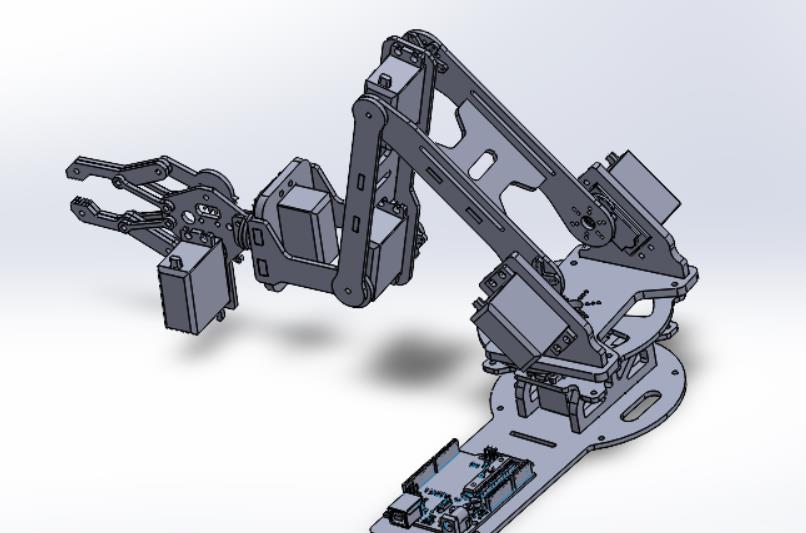
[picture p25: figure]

Conception final en 3D

### 2. L’impression 3D :

Après avoir finir la conception mécanique, nous allons choisir l’impression en 3D pour

réaliser le corps de notre robot en tenant compte du coût, de logement des composantes tel

que les moteurs, de logement des vis de maintien, du poids des pièces. Comparant par les

pièces fini trouvées dans le marché, les pièces par impression 3D sont plus robuste, plus

précise et plus belle esthétiquement.

Les figures ci-dessous présente les pièces non assemblées par l’impression en 3D :

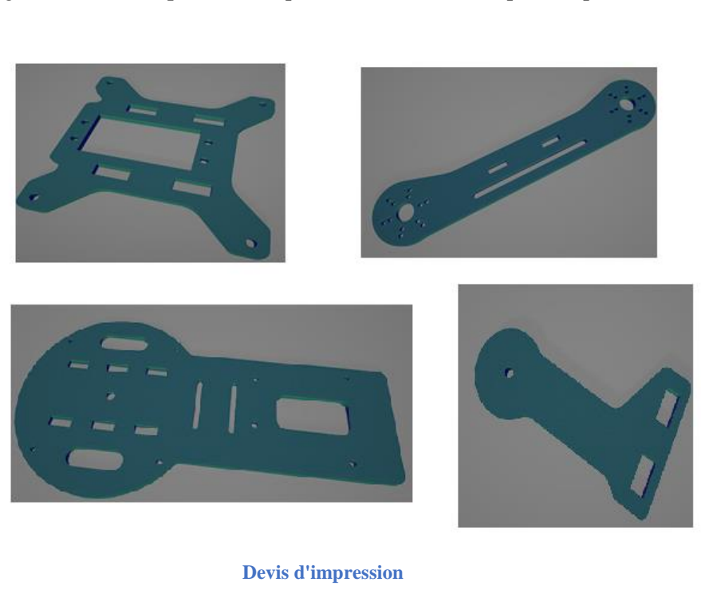
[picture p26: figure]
Devis d'impression

III. Conception électrique :
Nous avons employé deux sources pour la conception électrique, une pour le câblage de la carte Arduino, Bluetooth et les différents servomoteurs et l'autre pour le câblage avec le logiciel Proteus.

Nous avons élaboré le câblage ci-dessous :

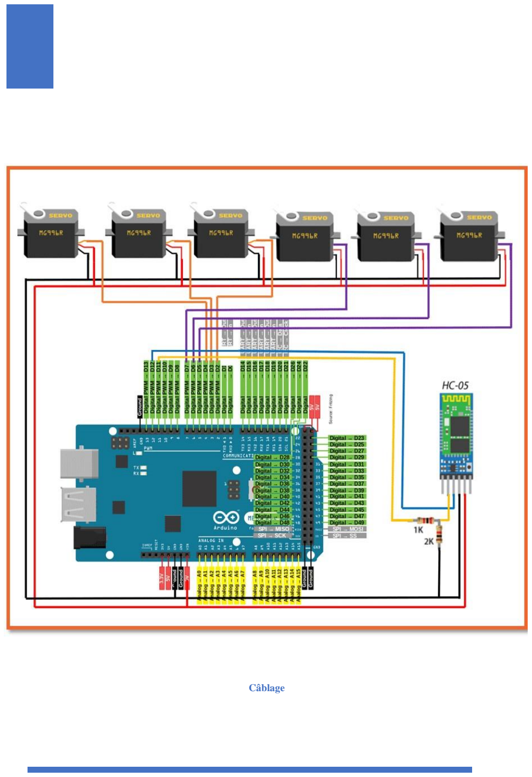
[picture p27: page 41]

IV. Conception électrique :

Une fois la conception est prête, nous procéderons au câblage électrique

Câblage

### 1. Présentation de logiciel « Proteus » :

La CAO électronique (https://fr.wikipedia.org/wiki/Conception_assist%C3%A9e_par_ordinateur_pour_l%27%C3%A9lectronique) Proteus¹, (https://fr.wikipedia.org/wiki/Proteus_(%C3%A9lectronique)#cite_note-1)2 (https://fr.wikipedia.org/wiki/Proteus_(%C3%A9lectronique)#cite_note-2)
est une suite logicielle, (https://fr.wikipedia.org/wiki/Logiciel) éditée par la société Labcenter

Electronics et revendue en France exclusivement par Multi power. Proteus est

actuellement (2020) la seule CAO électronique qui permet la conception d'un système

électronique complet et de le simuler, y compris avec le code des microcontrôleurs. Pour

ce faire, elle inclut un éditeur de schéma (ISIS), un outil de placement-routage (ARES),

un simulateur analogique-numérique, un environnement de développement intégré pour

microcontrôleurs, un module de programmation par algorigrammes ainsi qu'un éditeur

d'interface pour smartphone afin de piloter à distance des cartes Arduino (https://fr.wikipedia.org/wiki/Arduino) ou Raspberry Pi. (https://fr.wikipedia.org/wiki/Raspberry_Pi)

Câblage sur Proteus

V. Développement de l’application :

### 1. Présentation de l’application Mit app inventor :

App Inventor est un environnement et un langage de programmation (gratuit et libre

d'accès) pour réaliser des applications mobiles pour tablettes ou portables sous Android

(et IOS dans le courant du 2° trimestre 2018).

Il est très facile d'accès avec une méthode de programmation graphique par blocs

(blockly) qui évite les erreurs de syntaxe. Il exploite l'ensemble des ressources du

téléphone (capteurs, moyens de communication, ...) et il est ouvert sur le monde avec

l'accès au réseau et services Web, dont les bases de données.

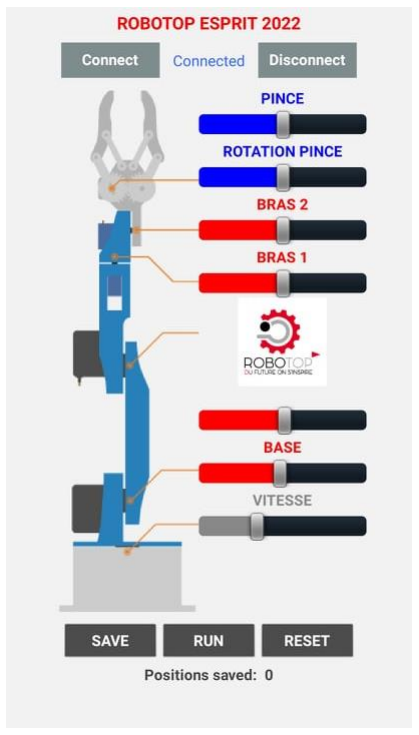
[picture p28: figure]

Interface de l’application

- Programmation de l’application

Le site Mittappinventor nous a permis de programmer l'application comme ceci :

VI. Développement de programmation Arduino :

Afin de commander notre ROBOTOP, nous devons gérer une connexion entre

l’application et la carte Arduino.

Nous avons utilisé le logiciel Arduino IDE . Le logiciel présente une interface qui nous a

permis de développer facilement les commandes qui peuvent être transférés sur la carte

en alimentant celle-ci. Le langage utilisé par le logiciel est basé sur le C.

### 1. Déclarations des variables :

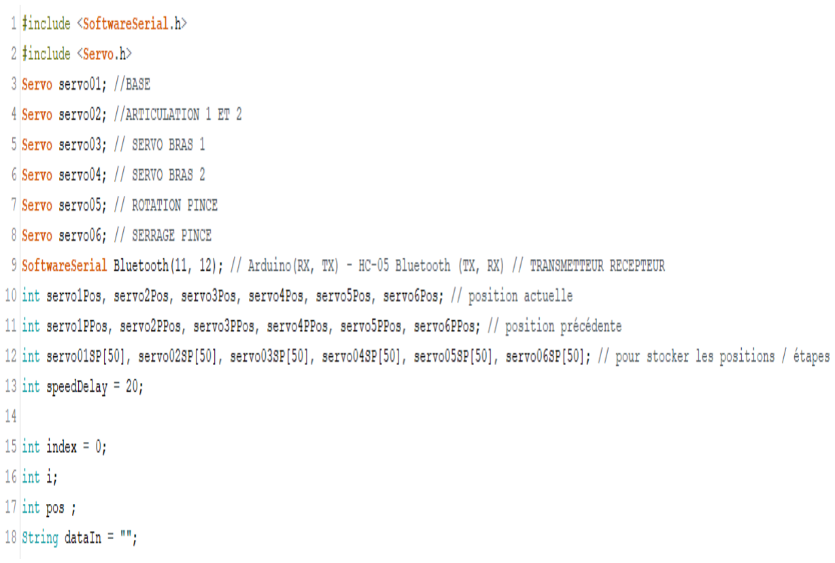
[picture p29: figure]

- Initialisations des servomoteurs :

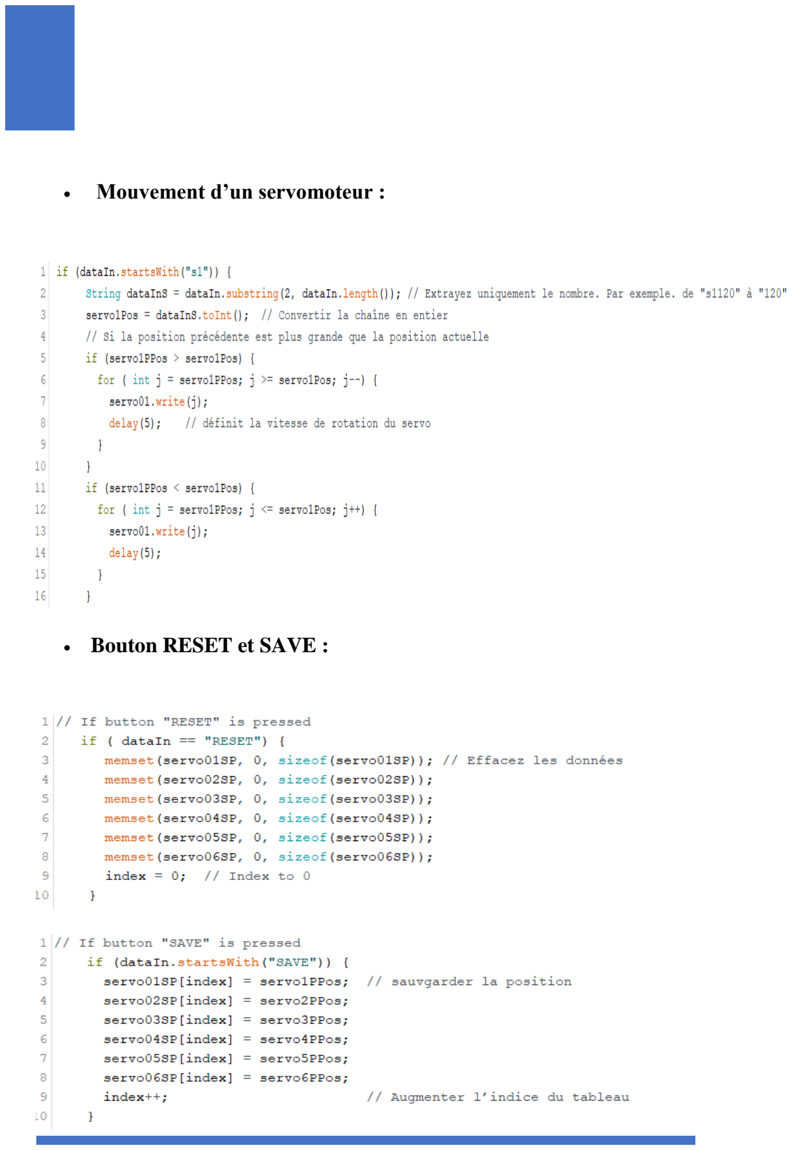
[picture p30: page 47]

- Mouvement d’un servomoteur :
- Bouton RESET et SAVE :

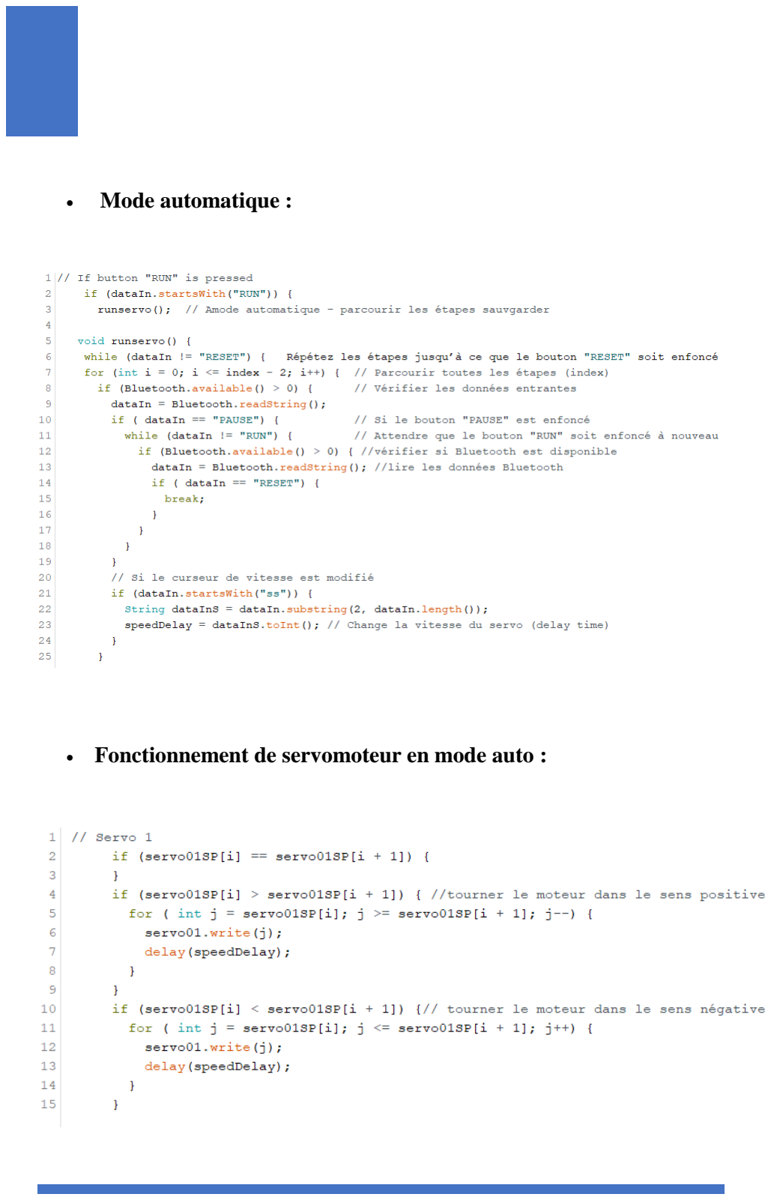
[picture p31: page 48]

- Mode automatique :
- Fonctionnement de servomoteur en mode auto :

VII. Conclusion :

Dans ce chapitre, nous avons pu décrire les différents éléments constitutifs du notre

robot manipulateur et injecter le programme dans la carte Arduino avec l’application.

## Conclusion générale

### Au terme de ce travail, nous avons pu concevoir et réaliser un bras

### manipulateur à 5 degrés de liberté que nous avons commandé avec une carte

Arduino méga.

### Ce travail nous a permis de mettre en valeur nos connaissances théoriques et

### pratique, que nous avons cumulées pendant toute la durée de nos études, il

### nous a permis aussi d’acquérir une expérience nouvelle dans la

### programmation des cartes Arduino. Nous nous sommes intéressés dans notre

travail à l’aspect théorique de la robotique mais surtout à l’aspect pratique,

### ce qui a présenté la difficulté majeure de notre démarche, et cela parce que

dans notre formation la théorie est prédominante.

### En s’intéressant à cet aspect nous avons pu mettre en relief les différentes

### notions théoriques que nous avons acquis. Il est évident que notre travail est

### loin d’être parfait, mais il peut constituer une base très intéressante pour les

promotions à venir qui voudront travailler sur ce type de sujet.

# ANNEXES :

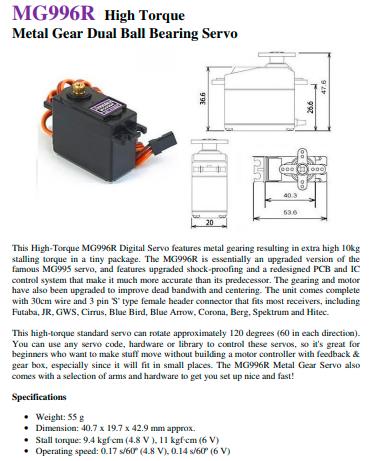
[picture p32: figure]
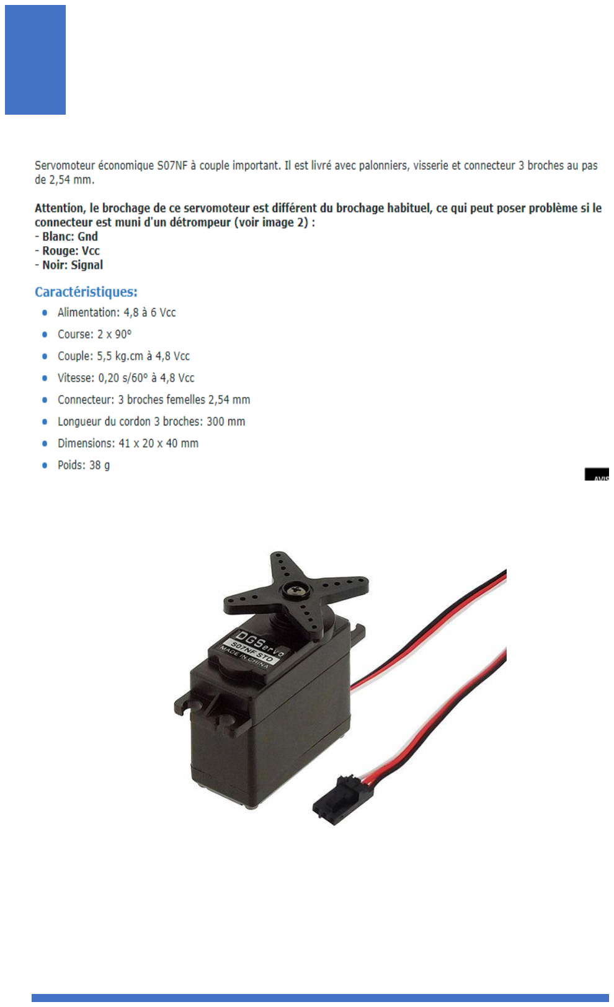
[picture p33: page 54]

## BIBLIOGRAPHIE

✓ | https://onvaessayer.org/appinventor/config/introduction.php
✓ | https://fr.wikipedia.org/wiki/MATLAB
✓ | https://www.google.com/search?q=interface+de+solidworks+
| 2020&rlz=1C1OKWM_frTN975TN975&sxsrf=ALiCzsZOtq
| I1fy2_IvnuhfafTqZKLVAbqw:1651755695650&source=lnm
| s&tbm=isch&sa=X&ved=2ahUKEwi-
| v_q7tcj3AhWjhv0HHSdtBPgQ_AUoAXoECAEQAw&biw=
| 1536&bih=706&dpr=1.25#imgrc=IVCKdM9E8iOXQM (https://www.google.com/search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)
✓ | https://www.google.com/imgres?imgurl=https%3A%2F%2Fi
| mage.slidesharecdn.com%2Fcoursrobotiquecomplet-
| 131115043229-phpapp02%2F85%2Fcours-robotique-
| complet-46-
| 320.jpg%3Fcb%3D1384490286&imgrefurl=https%3A%2F%
| 2Ffr.slideshare.net%2Fsouissi2013%2Fcours-robotique-
| complet&tbnid=kRum3IteF_iqYM&vet=10CEoQMyjwAWo
| XChMIkPf-
| xZnx9gIVAAAAAB0AAAAAEAM..i&docid=i_Sn24fcNm
| WclM&w=320&h=240&q=les%20robots%20manupilateur&
| ved=0CEoQMyjwAWoXChMIkPf-
| xZnx9gIVAAAAAB0AAAAAEAM (https://www.google.com/imgres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)
✓ | https://fr.wikipedia.org/wiki/Interface_en_ligne_de_comman
| de (https://fr.wikipedia.org/wiki/Interface_en_ligne_de_commande)
✓ | https://fr.wikipedia.org/wiki/Machine_%C3%A9lectrique#/m
| edia/Fichier:Motors01CJC.jpg (https://fr.wikipedia.org/wiki/Machine_%C3%A9lectrique#/media/Fichier:Motors01CJC.jpg)
✓ | https://howtomechatronics.com/tutorials/arduino/diy-arduino-
| robot-arm-with-smartphone-control/ (https://howtomechatronics.com/tutorials/arduino/diy-arduino-robot-arm-with-smartphone-control/)
✓ | https://www.ummto.dz/dspace/bitstream/handle/ummto/7737/
| MansouriRafik_KhelidA.pdf (https://www.ummto.dz/dspace/bitstream/handle/ummto/7737/MansouriRafik_KhelidA.pdf)

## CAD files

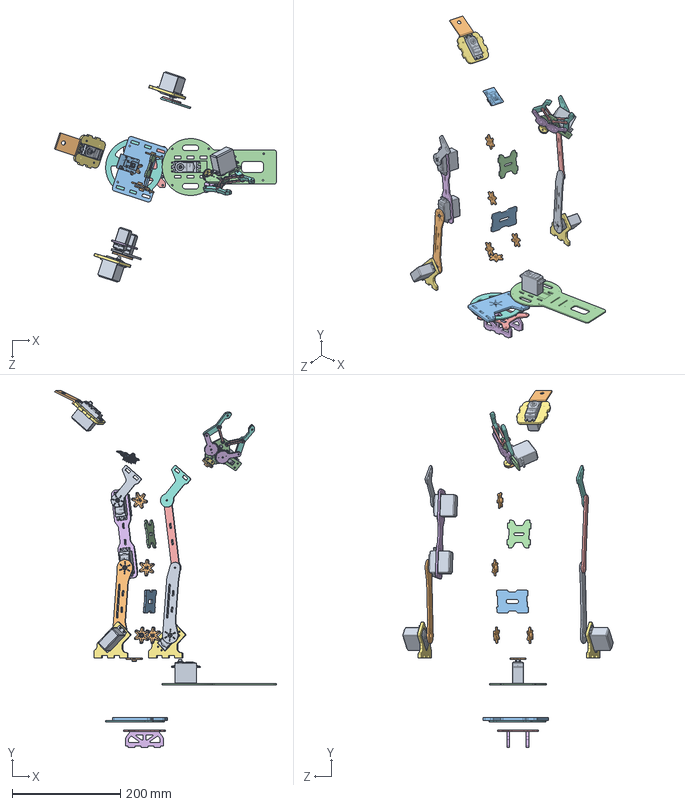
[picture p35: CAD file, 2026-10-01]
mechanical/robot-solidworks-source/Assemblage_pres_fini.SLDASM
409.7 x 658.4 x 388.5 mm
##Servo_MG_996R x 7
étoile servo x 5
RA 1.1. - Base Servo Mount
RA 1.1. - Base Servo Mount 1
RA 1.1. - Base Servo Mount 2
RA 1.1. - Base Servo Mount 3 x 2
RA 1.1. - Base Servo Mount R x 2
RA 1.1. - Base Servo Mount Support
RA 1.1. - Link 1 Arm L
RA 1.1. - Link 1 Arm R
RA 1.1. - Link 1 Support
RA 1.1. - Link 2 Support
RA 1.1. - Link 2 Arm L
RA 1.1. - Link 2 Arm R
RA 1.1. - Link 3 Arm Front
RA 1.1. - Link 3 Arm L
RA 1.1. - Link 3 Arm R
support esp32-cam
ESP3-CAM
base pince
[Fix 1] 1.Ref - Capit 2 x 4
[Fix 1] 1.Ref - Capit 4 x 2
[Fix 1] 1.Ref - Capit 5 x 2
[Fix 1] 1.Ref - Capit 1 x 4
Horn Bintang Standar
tête arbre servo

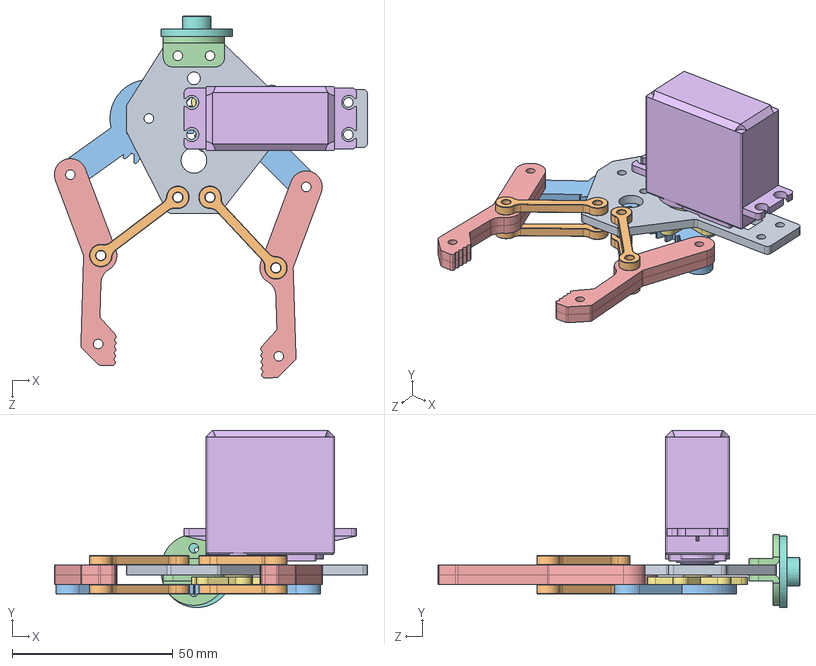
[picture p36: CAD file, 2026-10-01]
mechanical/robot-solidworks-source/pince.SLDASM
97.4 x 55.0 x 112.5 mm
base pince
[Fix 1] 1.Ref - Capit 2 x 4
[Fix 1] 1.Ref - Capit 4 x 2
[Fix 1] 1.Ref - Capit 5 x 2
[Fix 1] 1.Ref - Capit 1 x 4
##Servo_MG_996R
Horn Bintang Standar
tête arbre servo

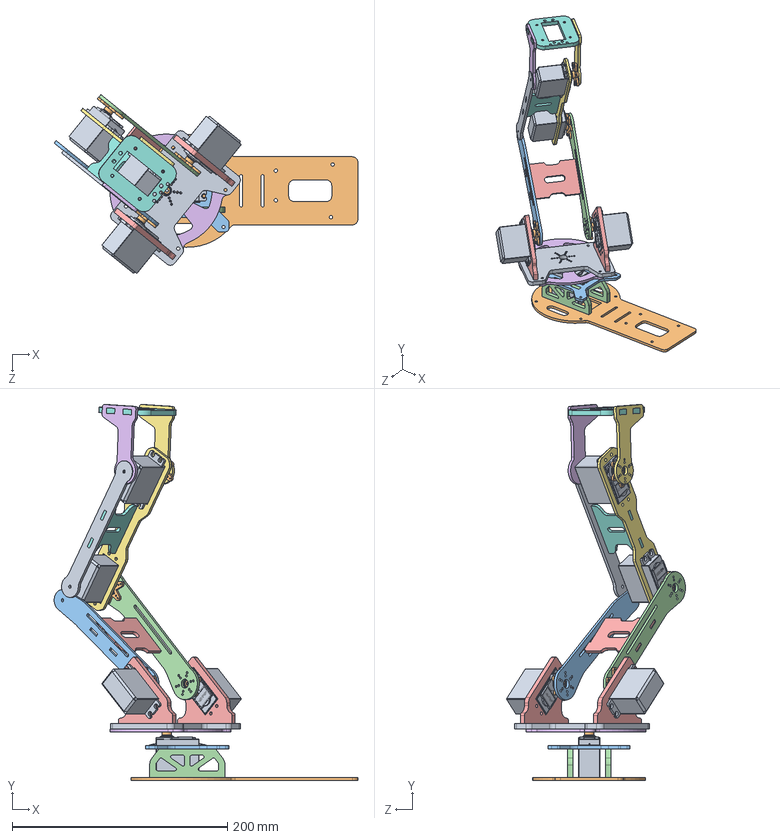
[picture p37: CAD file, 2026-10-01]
mechanical/robot-solidworks-source/Assemblage1.SLDASM
282.2 x 349.4 x 166.3 mm
RA 1.1. - Base Servo Mount
RA 1.1. - Base Servo Mount 1
RA 1.1. - Base Servo Mount 2
RA 1.1. - Base Servo Mount 3 x 2
RA 1.1. - Base Servo Mount R x 2
RA 1.1. - Base Servo Mount Support
RA 1.1. - Link 2 Arm R
RA 1.1. - Link 2 Support
##Servo_MG_996R x 5
étoile servo x 5
RA 1.1. - Link 1 Arm L
RA 1.1. - Link 1 Arm R
RA 1.1. - Link 1 Support
RA 1.1. - Link 3 Arm L
RA 1.1. - Link 3 Arm R
RA 1.1. - Link 3 Arm Front
RA 1.1. - Link 2 Arm L

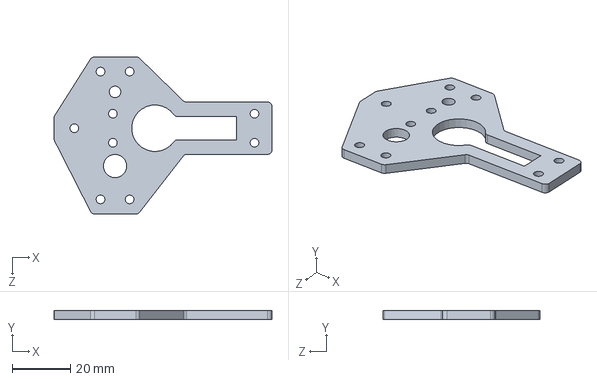
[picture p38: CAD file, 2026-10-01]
mechanical/robot-solidworks-source/base pince.SLDPRT
75.0 x 3.00 x 54.0 mm

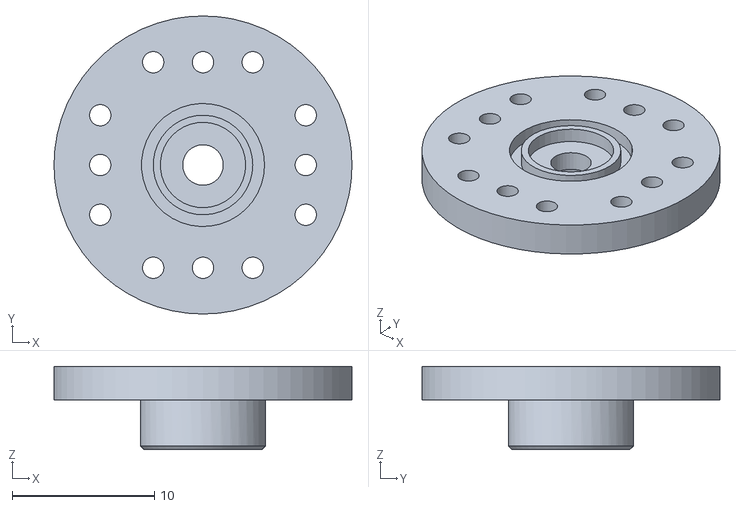
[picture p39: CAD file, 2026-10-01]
mechanical/stl-3d-printing/Horn Lingkaran Standar.STL
21.0 x 21.0 x 5.85

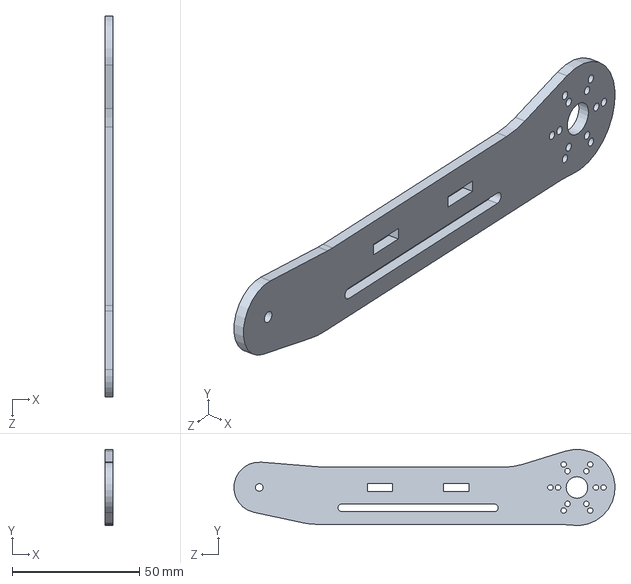
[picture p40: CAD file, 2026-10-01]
mechanical/robot-solidworks-source/RA 1.1. - Link 1 Arm L.sldprt
3.00 x 29.9 x 149.9 mm

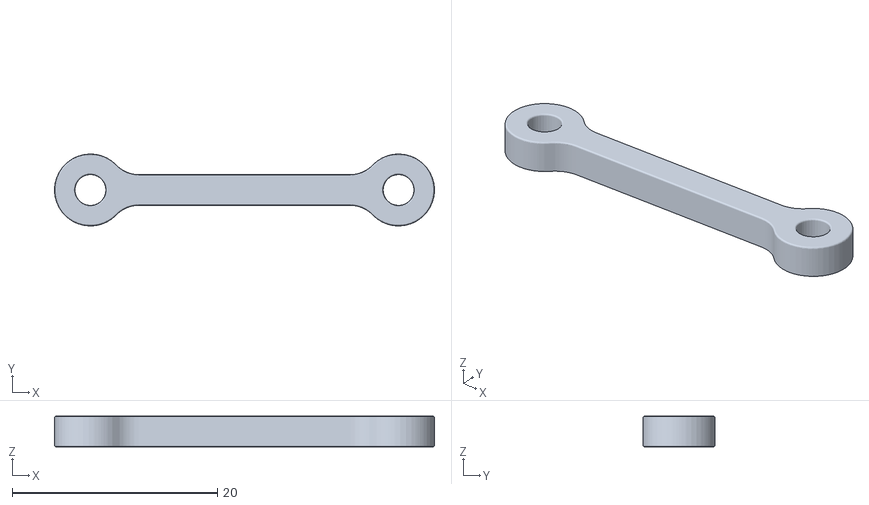
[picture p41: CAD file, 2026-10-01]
mechanical/stl-3d-printing/Pièce2.STL
37.0 x 6.99 x 3.00

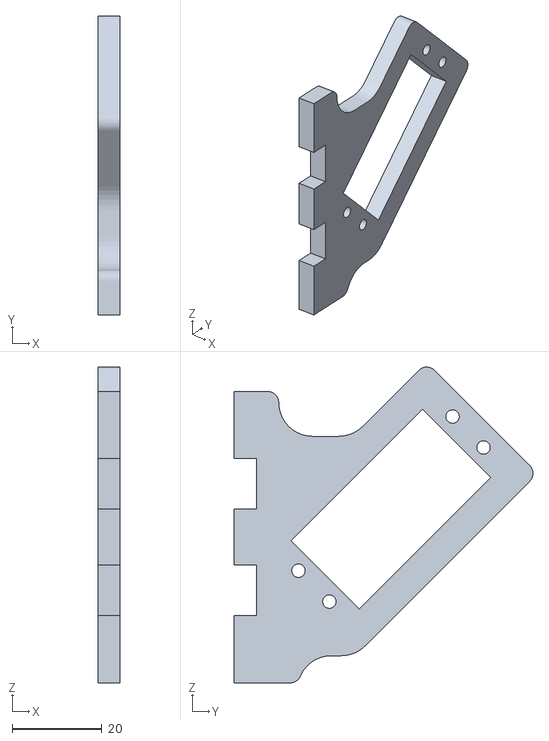
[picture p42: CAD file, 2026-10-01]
mechanical/stl-3d-printing/RA 1.1. - Base Servo Mount R.STL
5.00 x 66.7 x 70.4

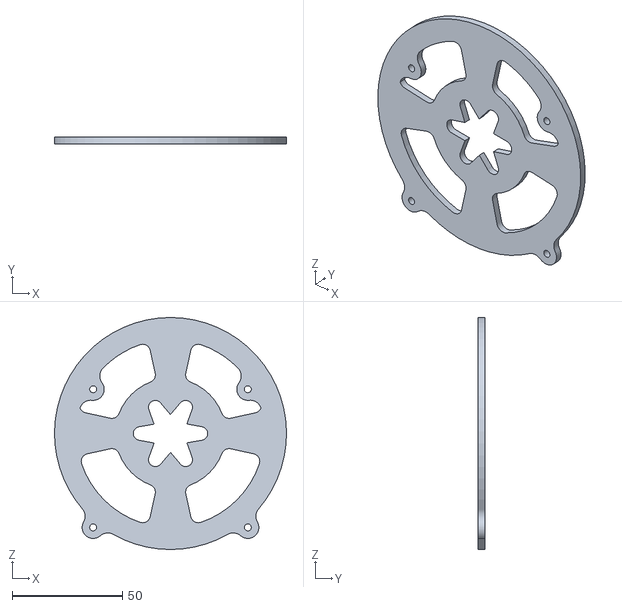
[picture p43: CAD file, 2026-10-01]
mechanical/stl-3d-printing/RA 1.1. - Base Servo Mount Support.STL
105.0 x 3.00 x 105.0

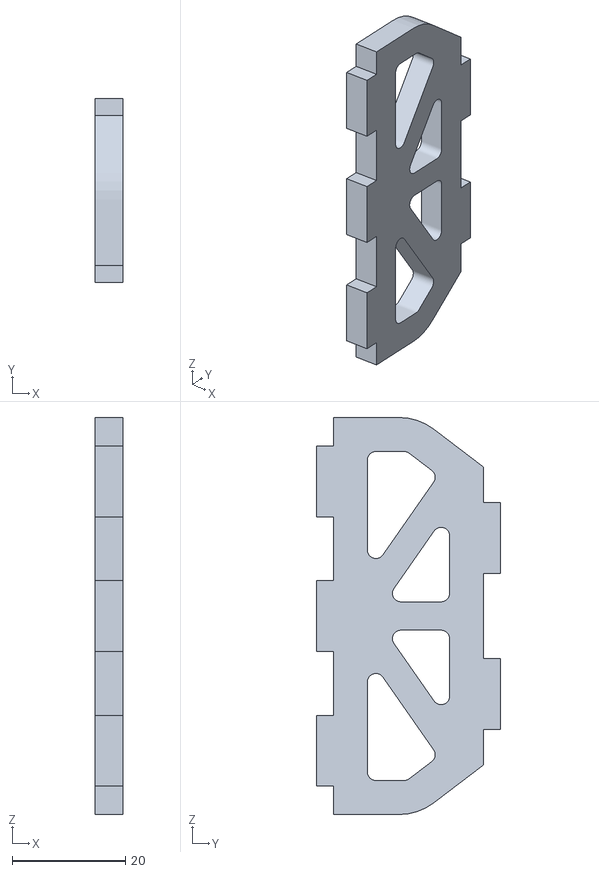
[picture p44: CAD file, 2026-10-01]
mechanical/stl-3d-printing/RA 1.1. - Base Servo Mount 3.STL
5.00 x 32.5 x 70.0

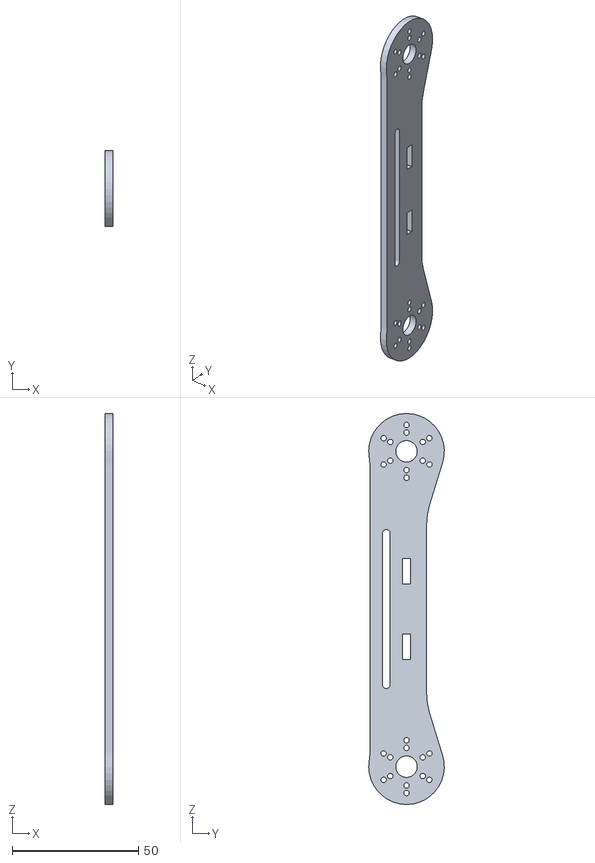
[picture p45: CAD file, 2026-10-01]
mechanical/stl-3d-printing/RA 1.1. - Link 1 Arm R.STL
3.00 x 30.0 x 155.0

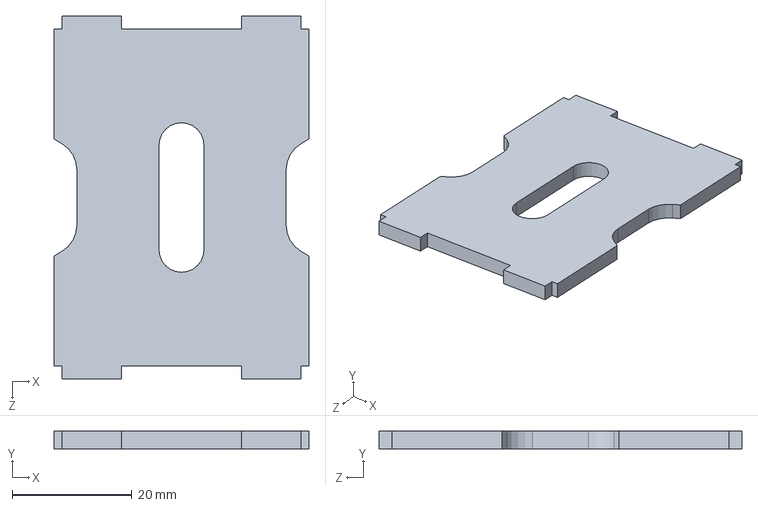
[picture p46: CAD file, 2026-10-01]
mechanical/robot-solidworks-source/RA 1.1. - Link 1 Support.sldprt
42.6 x 3.00 x 60.7 mm

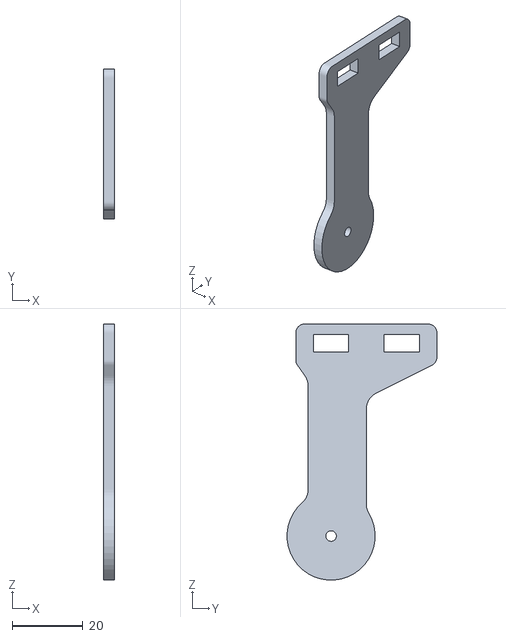
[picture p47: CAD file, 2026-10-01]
mechanical/stl-3d-printing/RA 1.1. - Link 3 Arm L.STL
3.00 x 42.5 x 72.6

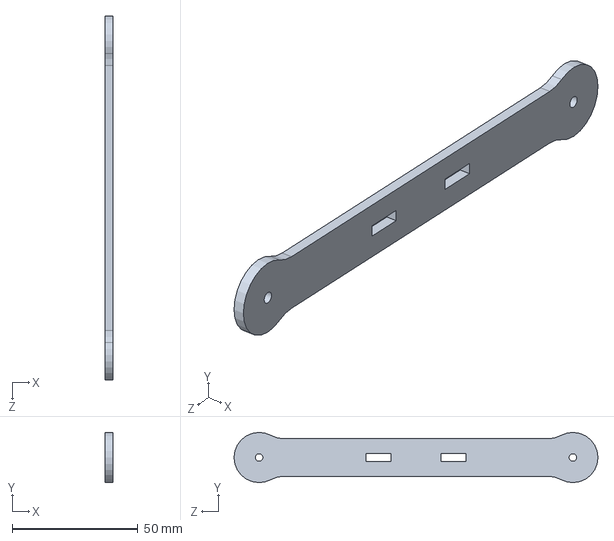
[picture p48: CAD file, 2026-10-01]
mechanical/robot-solidworks-source/RA 1.1. - Link 2 Arm L.sldprt
3.00 x 20.0 x 145.0 mm

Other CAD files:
mechanical/robot-solidworks-source/camera for ESP32.step.SLDASM
mechanical/robot-solidworks-source/[Fix 1] 1.Ref - Capit 5.sldprt
mechanical/robot-solidworks-source/[Fix 1] 1.Ref - Capit 1.sldprt
mechanical/stl-3d-printing/Pièce6.STL
mechanical/robot-solidworks-source/##Servo_MG_996R.SLDPRT
mechanical/robot-solidworks-source/Arduino UNO.sldprt
mechanical/robot-solidworks-source/ESP3-CAM v4.step
mechanical/robot-solidworks-source/ESP3-CAM.SLDPRT
mechanical/robot-solidworks-source/ESP3-CAM.STEP
mechanical/robot-solidworks-source/Horn Bintang Standar.sldprt
mechanical/robot-solidworks-source/Horn Lingkaran Standar.sldprt
mechanical/robot-solidworks-source/RA 1.1. - Base Servo Mount 1.sldprt
mechanical/robot-solidworks-source/RA 1.1. - Base Servo Mount 2.sldprt
mechanical/robot-solidworks-source/RA 1.1. - Base Servo Mount 3.sldprt
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

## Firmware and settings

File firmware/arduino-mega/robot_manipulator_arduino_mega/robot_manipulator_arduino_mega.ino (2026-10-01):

#include <SoftwareSerial.h>
#include <Servo.h>
Servo servo01; //BASE 
Servo servo02; //ARTICULATION 1 ET 2
Servo servo03; // SERVO BRAS 1
Servo servo04; // SERVO BRAS 2 
Servo servo05; // ROTATION PINCE
Servo servo06; // SERRAGE PINCE
Servo servo07;
SoftwareSerial Bluetooth(11, 12); // Arduino(RX, TX) - HC-05 Bluetooth (TX, RX) // TRANSMETTEUR RECEPTEUR
int servo1Pos, servo2Pos, servo3Pos, servo4Pos,servo7Pos ,servo5Pos, servo6Pos; // position actuelle
int servo1PPos, servo2PPos, servo3PPos,servo7PPos, servo4PPos, servo5PPos, servo6PPos; // position précédente
int servo01SP[50], servo02SP[50],servo07SP[50], servo03SP[50], servo04SP[50], servo05SP[50], servo06SP[50]; // pour stocker les positions / étapes
int speedDelay = 20;

int index = 0;
int i;
int pos ;
String dataIn = "";
void setup() {
  servo01.attach(4);
  servo02.attach(5);
  servo03.attach(7);
  servo04.attach(8);
  servo05.attach(9);
  servo06.attach(10);
  servo07.attach(6);
  Bluetooth.begin(9600); 
  Bluetooth.setTimeout(10);
  delay(50);
//  position initial
  servo1PPos = 60;
  servo01.write(servo1PPos);
  servo2PPos = 60;
  servo02.write(servo2PPos);
  servo3PPos = 60;
  servo03.write(servo3PPos);
  servo4PPos = 60;
  servo04.write(servo4PPos);
  servo5PPos = 60;
  servo05.write(servo5PPos);
  servo6PPos = 60;
  servo06.write(servo6PPos);
  servo7PPos = 60;
  servo07.write(servo7PPos);
  
}
void loop() {
  // Vérifier les données entrantes
  if (Bluetooth.available() > 0) {
    dataIn = Bluetooth.readString();  // Lire les données sous forme de chaîne
    // si "Waist" curseur a changé de valeur - Déplacez le servo 1 en position
    if (dataIn.startsWith("s1")) {
      String dataInS = dataIn.substring(2, dataIn.length()); // Extrayez uniquement le nombre. Par exemple. de "s1120" à "120"
      servo1Pos = dataInS.toInt();  // Convertir la chaîne en entier
      // Si la position précédente est plus grande que la position actuelle
      if (servo1PPos > servo1Pos) {
        for ( int j = servo1PPos; j >= servo1Pos; j--) {   
          servo01.write(j);
          delay(20);    // définit la vitesse de rotation du servo
          Serial.print(j);
        }
      }
      // If previous position is smaller then current position
      if (servo1PPos < servo1Pos) {
        for ( int j = servo1PPos; j <= servo1Pos; j++) {  
          servo01.write(j);
          delay(20);
        }
      }
      servo1PPos = servo1Pos;   // définir la position actuelle comme position précédente
     
    }
    
    // Move Servo 2
    if (dataIn.startsWith("s2")) {
      String dataInS = dataIn.substring(2, dataIn.length());
      servo2Pos = dataInS.toInt();
      if (servo2PPos > servo2Pos) {
        int x = servo7PPos;
        for ( int j = servo2PPos; j >= servo2Pos; j--) {
          if (j != servo2PPos){
          x++;}
          servo07.write(x);
          servo02.write(j);
          delay(20); 
        }
      }
      if (servo2PPos < servo2Pos) {
        int x = servo7PPos;
        for ( int j = servo2PPos; j <= servo2Pos; j++) {
          if (j != servo2PPos){
          x--;}
          servo07.write(x);
          servo02.write(j);
          delay(20);
        }
      }
      servo2PPos = servo2Pos;
      servo7PPos = servo7Pos;
    
    }
    // Move Servo 3
    if (dataIn.startsWith("s3")) {
      String dataInS = dataIn.substring(2, dataIn.length());
      servo3Pos = dataInS.toInt();
      if (servo3PPos > servo3Pos) {
        for ( int j = servo3PPos; j >= servo3Pos; j--) {
          servo03.write(j);
          delay(20);
        }
      }
      if (servo3PPos < servo3Pos) {
        for ( int j = servo3PPos; j <= servo3Pos; j++) {
          servo03.write(j);
          delay(20);
        }
      }
      servo3PPos = servo3Pos;
    }
    // Move Servo 4
    if (dataIn.startsWith("s4")) {
      String dataInS = dataIn.substring(2, dataIn.length());
      servo4Pos = dataInS.toInt();
      if (servo4PPos > servo4Pos) {
        for ( int j = servo4PPos; j >= servo4Pos; j--) {
          servo04.write(j);
          delay(20);
        }
      }
      if (servo4PPos < servo4Pos) {
        for ( int j = servo4PPos; j <= servo4Pos; j++) {
          servo04.write(j);
          delay(20);
        }
      }
      servo4PPos = servo4Pos;
    }
    // Move Servo 5
    if (dataIn.startsWith("s5")) {
      String dataInS = dataIn.substring(2, dataIn.length());
      servo5Pos = dataInS.toInt();
      if (servo5PPos > servo5Pos) {
        for ( int j = servo5PPos; j >= servo5Pos; j--) {
          servo05.write(j);
          delay(20);
        }
      }
      if (servo5PPos < servo5Pos) {
        for ( int j = servo5PPos; j <= servo5Pos; j++) {
          servo05.write(j);
          delay(20);
        }
      }
      servo5PPos = servo5Pos;
    }
    // Move Servo 6
    if (dataIn.startsWith("s6")) {
      String dataInS = dataIn.substring(2, dataIn.length());
      servo6Pos = dataInS.toInt();
      if (servo6PPos > servo6Pos) {
        for ( int j = servo6PPos; j >= servo6Pos; j--) {
          servo06.write(j);
          delay(20);
        }
      }
      if (servo6PPos < servo6Pos) {
        for ( int j = servo6PPos; j <= servo6Pos; j++) {
          servo06.write(j);
          delay>(20);
        }
      }
      servo6PPos = servo6Pos; 
    }
    // If button "SAVE" is pressed
    if (dataIn.startsWith("SAVE")) {
      servo01SP[index] = servo1PPos;  // save position into the array
      servo02SP[index] = servo2PPos;
      servo03SP[index] = servo3PPos;
      servo04SP[index] = servo4PPos;
      servo05SP[index] = servo5PPos;
      servo06SP[index] = servo6PPos;
      index++;                        // Increase the array index
    }
    // If button "RUN" is pressed
    if (dataIn.startsWith("RUN")) {
      runservo();  // Automatic mode - run the saved steps 
    }
    if ( dataIn == "RESET") {
      memset(servo01SP, 0, sizeof(servo01SP)); // Effacez les données 
      memset(servo02SP, 0, sizeof(servo02SP));
      memset(servo03SP, 0, sizeof(servo03SP));
      memset(servo04SP, 0, sizeof(servo04SP));
      memset(servo05SP, 0, sizeof(servo05SP));
      memset(servo06SP, 0, sizeof(servo06SP));
      index = 0;  // Index to 0
    }
   }}
    // Automatic mode custom function - run the saved steps
void runservo() {
  while (dataIn != "RESET") {   // Run the steps over and over again until "RESET" button is pressed
    for (int i = 0; i <= index - 2; i++) {  // Run through all steps(index)
      if (Bluetooth.available() > 0) {      // Check for incomding data
        dataIn = Bluetooth.readString();
        if ( dataIn == "PAUSE") {           // If button "PAUSE" is pressed
          while (dataIn != "RUN") {         // Wait until "RUN" is pressed again
            if (Bluetooth.available() > 0) {
              dataIn = Bluetooth.readString();
              if ( dataIn == "RESET") {     
                break;
              }
            }
          }
        }
        // If speed slider is changed
        if (dataIn.startsWith("ss")) {
          String dataInS = dataIn.substring(2, dataIn.length());
          speedDelay = dataInS.toInt(); // Change servo speed (delay time)
        }
      }
      // Servo 1
      if (servo01SP[i] == servo01SP[i + 1]) {
      }
      if (servo01SP[i] > servo01SP[i + 1]) {
        for ( int j = servo01SP[i]; j >= servo01SP[i + 1]; j--) {
          servo01.write(j);
          delay(speedDelay);
        }
      }
      if (servo01SP[i] < servo01SP[i + 1]) {
        for ( int j = servo01SP[i]; j <= servo01SP[i + 1]; j++) {
          servo01.write(j);
          delay(speedDelay);
        }
      }

      // Servo 2
      if (servo02SP[i] == servo02SP[i + 1]) {
      }
      if (servo02SP[i] > servo02SP[i + 1]) {
        for ( int j = servo02SP[i]; j >= servo02SP[i + 1]; j--) {
          servo02.write(j);
          delay(speedDelay);
        }
      }
      if (servo02SP[i] < servo02SP[i + 1]) {
        for ( int j = servo02SP[i]; j <= servo02SP[i + 1]; j++) {
          servo02.write(j);
          delay(speedDelay);
        }
      }

      // Servo 3
      if (servo03SP[i] == servo03SP[i + 1]) {
      }
      if (servo03SP[i] > servo03SP[i + 1]) {
        for ( int j = servo03SP[i]; j >= servo03SP[i + 1]; j--) {
          servo03.write(j);
          delay(speedDelay);
        }
      }
      if (servo03SP[i] < servo03SP[i + 1]) {
        for ( int j = servo03SP[i]; j <= servo03SP[i + 1]; j++) {
          servo03.write(j);
          delay(speedDelay);
        }
      }

      // Servo 4
      if (servo04SP[i] == servo04SP[i + 1]) {
      }
      if (servo04SP[i] > servo04SP[i + 1]) {
        for ( int j = servo04SP[i]; j >= servo04SP[i + 1]; j--) {
          servo04.write(j);
          delay(speedDelay);
        }
      }
      if (servo04SP[i] < servo04SP[i + 1]) {
        for ( int j = servo04SP[i]; j <= servo04SP[i + 1]; j++) {
          servo04.write(j);
          delay(speedDelay);
        }
      }

      // Servo 5
      if (servo05SP[i] == servo05SP[i + 1]) {
      }
      if (servo05SP[i] > servo05SP[i + 1]) {
        for ( int j = servo05SP[i]; j >= servo05SP[i + 1]; j--) {
          servo05.write(j);
          delay(speedDelay);
        }
      }
      if (servo05SP[i] < servo05SP[i + 1]) {
        for ( int j = servo05SP[i]; j <= servo05SP[i + 1]; j++) {
          servo05.write(j);
          delay(speedDelay);
        }
      }

      // Servo 6
      if (servo06SP[i] == servo06SP[i + 1]) {
      }
      if (servo06SP[i] > servo06SP[i + 1]) {
        for ( int j = servo06SP[i]; j >= servo06SP[i + 1]; j--) {
          servo06.write(j);
          delay(speedDelay);
        }
      }
      if (servo06SP[i] < servo06SP[i + 1]) {
        for ( int j = servo06SP[i]; j <= servo06SP[i + 1]; j++) {
          servo06.write(j);
          delay(speedDelay);
        }
      }
    }
  }
}
  
